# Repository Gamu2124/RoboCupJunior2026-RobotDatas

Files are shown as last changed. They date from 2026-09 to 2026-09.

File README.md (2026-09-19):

# AIR - RoboCupJunior2026 RobotData Repository

RoboCupJunior Soccer Lightweight 2026 シーズンにおいて、**ジャパンオープン優勝**、そして世界大会（韓国・仁川）で**競技優勝・総合優勝・コミュニティ賞**を達成したロボット「AIR」の**設計・開発データを公開するリポジトリ**です。

This repository contains the **design, hardware, and software data of AIR**, the **RoboCupJunior Soccer Lightweight 2026 Japan Open Champion and World Championship Champion**.

---
# 概要 / Overview

本リポジトリは、**次世代のRCJコミュニティおよび学生ロボティクスエンジニアへの情報共有**を目的として公開されています。

2026シーズンの開発で使用した**回路設計、組み込みソフトウェア、マルチマイコンによる分散処理システム、3D CADデータ**など、AIRのロボット開発に関する設計データを公開しています。

We open-source **AIR's robot design and development data** to support the global RCJ community and future student roboticists.

The repository includes **custom PCB designs, multi-MCU embedded firmware, and 3D CAD models** used in the development of AIR during the 2026 season.

---

<table align="center">
  <tr>
    <td align="center">
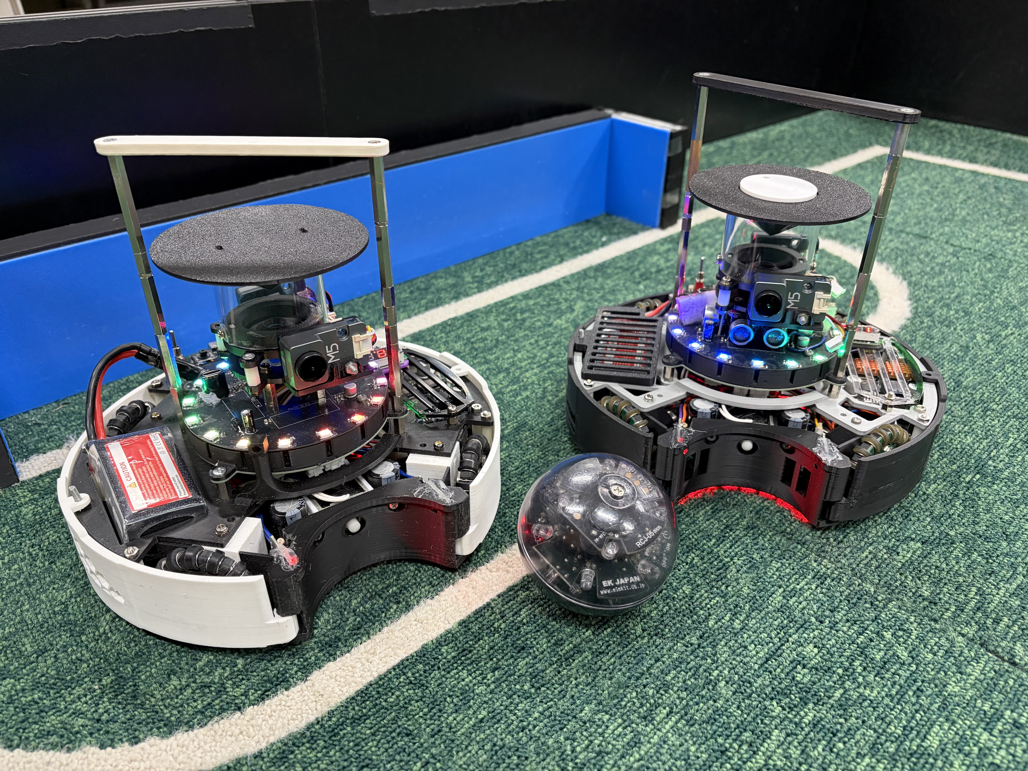
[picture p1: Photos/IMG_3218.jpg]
      
      <br>
      <b>Japan Open 2026</b>
    </td>
    <td align="center">
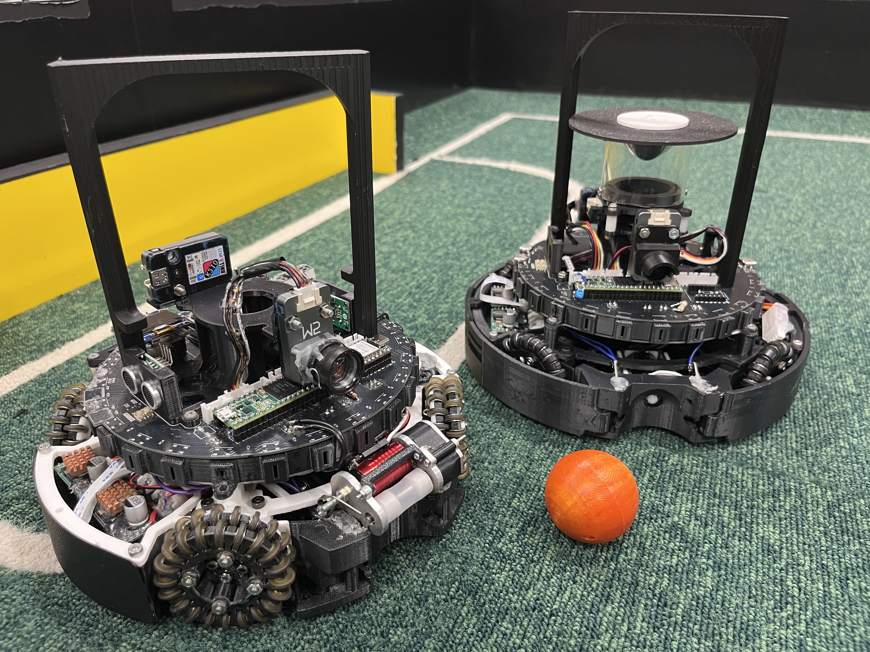
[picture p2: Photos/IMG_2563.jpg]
      
      <br>
      <b>World Championship 2026</b>
    </td>
  </tr>
</table>

---

# 大会実績 / Competition Results

* **RoboCupJunior Japan Open 2026**

  * 🥇 **競技 優勝 / 1st Place**

* **RoboCup World Championship 2026**

  * **Incheon, Republic of Korea**
  * 🥇 **競技 優勝 / Individual 1st Place**
  * 🏆 **総合 優勝 / Overall 1st Place**
  * 🏅 **コミュニティ賞 / Community Award**

---

# 技術的ハイライト / Technical Highlights

AIRのシステムは、**高速なセンサ処理と制御、複数のマイコンへの処理分散、そして競技環境での安定動作**を重視して設計されています。

* **Teensy 4.1を中心としたマルチマイコン分散処理**

  メインマイコンとして**Teensy 4.1**を使用し、複数のUARTを介してボール検出、ライン検出、壁面距離計測、UIなどの処理をサブマイコンへ分散しています。

* **24基のTSSP58038による高密度ボール検出**

  **RP2350Aと24個の赤外線センサ**を使用し、複数方向からのボール検出を高速に行います。得られたセンサ情報から**ボールの方向や距離を推定**し、ロボットの走行制御に利用しています。

* **FreeRTOSを用いた非ブロッキング超音波計測**

  **XIAO ESP32-S3上でFreeRTOSを利用**し、超音波センサによる壁面距離計測をメインの制御処理から分離しています。

* **電源・回路の安定性を重視した設計**

  **DCDCコンバータによる電源系統の分離**、大電流を扱うキッカー回路、複数のマイコン・センサ・モータドライバを統合した電源および信号系統を設計しています。

* **世界大会でのリモートシステムへの対応**

  **世界大会で使用された公式リモートシステム**に対応するための通信・制御機能を実装しています。

---

# リポジトリ構成 / Repository Structure

```text
.
├── Circuit/             # 回路・PCB設計データ (KiCad)
├── Hardware/            # 3D CAD・機械設計データ
├── Program/             # 組み込みソフトウェア・プログラム
├── PresentationSheet/   # プレゼンテーション・資料
├── .gitattributes
└── README.md
```

---

# ハードウェア仕様とシステム進化 / Hardware Architecture & Evolution

AIRのハードウェア構成は、**ジャパンオープンから世界大会（Incheon）にかけて大幅に進化**しました。

| ユニット / System | Japan Open モデル | World Championship (Incheon) モデル |
| --- | --- | --- |
| **Main MCU** | Teensy 4.1 | Teensy 4.1 |
| **Ball Sub MCU & Sensors** | ATmega32U4 + TSSP4038 | **RP2350A + TSSP58038 × 24** |
| **Line Sub MCU & Sensors** | ATmega2560 + B19H1LS / LM393 | **RP2350B + B19H1LS / LM393** |
| **Wall / US MCU** | XIAO ESP32-S3 | XIAO ESP32-S3 |
| **UI & Remote Control** | ESP32 WROOM-32E + OLED + NeoPixel | **XIAO ESP32-S3 + OLED** |
| **Motor Driver** | DRV8432 | **DRV8432** |
| **Kicker System** | CB1037 + Pch/Nch MOSFET | **CB1037 + AQW212 + XL6009** |
| **Power Distribution** | LM2576系電源 | **AP64500SP系電源** |

---

# ソフトウェア機能 / Software Architecture

主に**C/C++およびPython**を用いて開発された、**マルチマイコン分散処理によるロボット制御システム**です。

* **Ball Tracking**

  **24個のTSSP58038**から得られるセンサ情報をRP2350Aで高速処理し、**ボールの方向および距離を推定**します。

* **Line Keep**

  **B19H1LSおよびLM393**を使用したラインセンサシステムにより、フィールド上の白線を検出し、フィールド外への逸脱を防止します。

* **Wall Distance**

  ESP32-S3上で**FreeRTOS**を利用し、超音波センサによる壁面距離計測をバックグラウンドで実行します。

* **Motion Control**

  **IMU（BNO055）から得られる姿勢情報を利用したPIDベースの全方向移動制御**を行います。

* **Strategy State Machine**

  ボール検出、ライン検出、壁面距離、ロボットの状態などの情報をもとに、**試合中の動作を状態機械として制御**します。

* **World Championship Remote Control**

  **世界大会で使用された公式リモートシステムに対応した通信・制御機能**を実装しています。

---

# 開発環境・使用設備 / Development Environment & Equipment

### Software Tools

* **3D CAD**: Autodesk Fusion 360
* **EDA (PCB Design)**: KiCad
* **IDE / Programming**: Visual Studio Code / MaixPy IDE
* **Presentation & Media**: Canva

### Hardware & Manufacturing Equipment

* **3D Printers**: Bambu Lab A1 mini / Bambu Lab P1S / Flashforge Adventurer 5M
* **PCB Fabrication**: JLCPCB
* **Machining / Tools**: 小型CNC加工機

---

# CAD設計データ / CAD Models

AIRを構成する**カスタム機械部品をAutodesk Fusion 360で設計**しています。

主な設計データには以下が含まれます。

* **シャーシ構造** / Chassis
* **キッカーユニット** / Kicker Unit
* **センサマウント各種** / Sensor Mounts
* **オムニホイールモジュール** / Omni Wheel Modules
* **ドリブラー機構** / Dribbler Mechanism

---

# 公開基板データ / PCB Designs

ロボットに使用した**自作基板のKiCad設計データ**を公開しています。

## 日本大会機

1. **メイン基板 (`main_unit`)**
   各種マイコン・センサ・制御系を統合したメイン基板

2. **ボールセンサー基板 (`ball_unit`)**
   **TSSP4038およびATmega32U4**を搭載したボール検出基板

3. **ラインセンサー基板 (`line_unit`)**
   **B19H1LS、LM393、ATmega2560**を搭載したライン検出基板

4. **電源基板 (`power_unit`)**
   **LM2576**を使用した電源基板

5. **モータドライバ基板 (`md_unit`)**
   **DRV8432**を使用したモータドライバ基板

6. **キッカー制御基板 (`kicker_unit`)**
   キッカー用の**大電流スイッチング・絶縁回路**

## 世界大会機

1. **メイン基板 (`main_unit`)**
   各種マイコン・IMU・UIなどを統合したメイン基板

2. **ボールセンサー基板 (`ball_unit`)**
   **TSSP58038 × 24およびRP2350A**を搭載した高密度ボール検出基板

3. **ラインセンサー基板 (`line_unit`)**
   **B19H1LS、LM393、RP2350B**を搭載したライン検出基板

4. **電源基板 (`power_unit`)**
   **AP64500SP**を使用した電源基板

5. **モータドライバ基板 (`md_unit`)**
   **DRV8432**を使用したモータドライバ基板

6. **キッカー制御基板 (`kicker_unit`)**
   **昇圧回路、大電流スイッチング回路、AQW212**を使用したキッカー制御基板

---

# スポンサー / Sponsors

本プロジェクトの活動を支援していただいたスポンサー・団体の皆様に、心より感謝申し上げます。

* **JLCPCB**
  https://jlcpcb.com/

* **DigiKey**
  https://www.digikey.jp/

* **株式会社人機一体**
  https://www.jinki.jp/

* **MAXON**
  https://maxonjapan.com/

* **タカハ機工株式会社**
  https://www.takaha.co.jp/

* **株式会社システムアイインターナショナル**
  https://www.systemi.com/

* **ライフ&キャリアコンサルティング LACIQUE**
  https://www.lacique.com/

* **医療法人社団 翠会 水口病院**
  https://www.minakuchi-hp.or.jp/

* **JOJISTABLE**
  https://x.com/JojiStable

* **立命館守山高校 & 立命館大学**
  https://www.mrc.ritsumei.ac.jp/
  https://www.ritsumei.ac.jp/

---

# チーム情報・お問い合わせ / Team Information & Contact

## AIR

**RoboCupJunior Soccer Lightweight & Infrared Team from Japan**

**World Champion 2026**

### チーム実績 / Team History

* **2025 シーズン**

  * RoboCupJunior Japan Open 2025 🥉 **3位**
  * RoboCup World Championship 2025
    Salvador, Brazil 🥉 **Individual 3rd Place**

* **2026 シーズン**

  * RoboCupJunior Japan Open 2026 🥇 **優勝**
  * RoboCup World Championship 2026
    Incheon, Republic of Korea 🏆 **Individual 1st Place**
  * 🏅 **Community Award**

---

### お問い合わせ・ご質問 / Contact Information

本リポジトリの内容、設計データ、その他技術的なご質問やお問い合わせについては、以下よりご連絡ください。

* **X (Twitter) DM**: [@Air_Gamu_rcj](https://x.com/Air_Gamu_rcj)

* **Email**: [airkorea2026@gmail.com](mailto:airkorea2026@gmail.com)

### 公式メディア・SNS / Links

* **X (Twitter)**: [@Air_3838](https://x.com/Air_3838)

* **YouTube**: [AIR-RCJ Channel](https://www.youtube.com/@AIR-RCJ)

* **note**: [AIR Official note](https://note.com/air_rcj)

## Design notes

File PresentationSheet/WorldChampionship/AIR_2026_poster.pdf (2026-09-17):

# LiPo & SPEED DROP COMPENSATION

# TEAM ABSTRACT

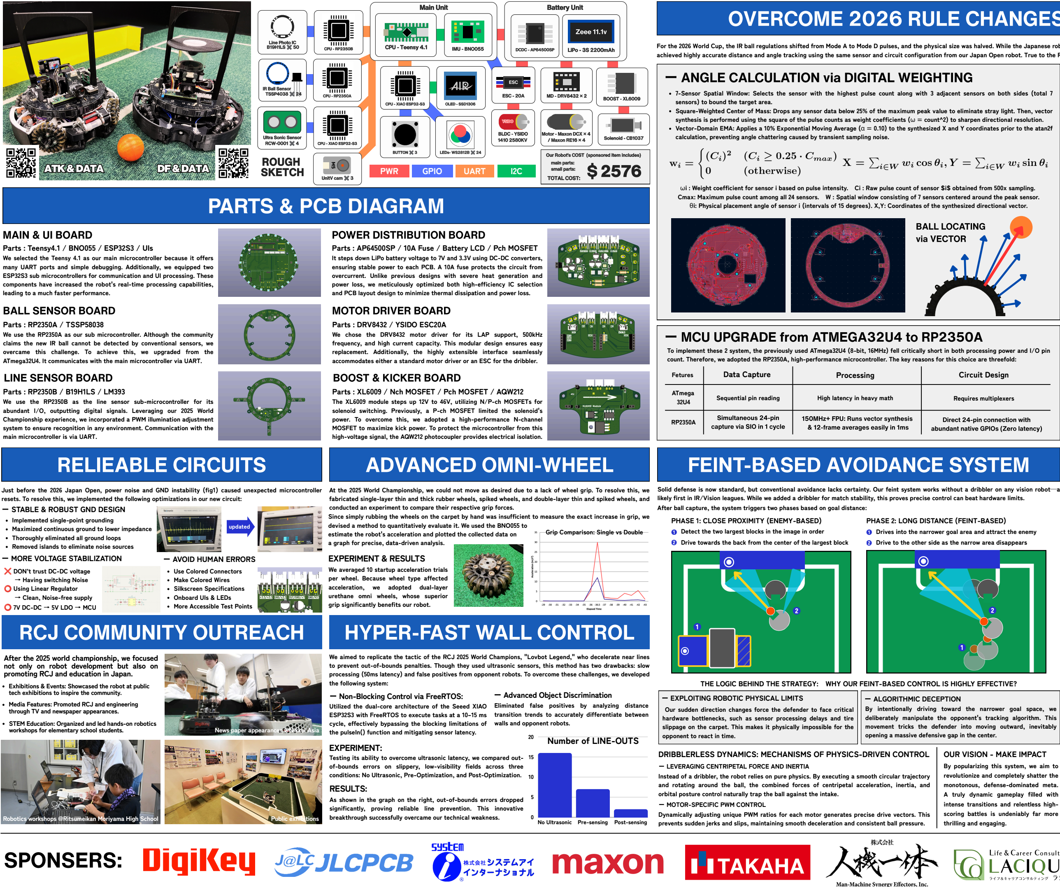
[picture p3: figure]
PARTS & PCB DIAGRAM; RELIEABLE CIRCUITS; RCJ COMMUNITY OUTREACH; ー STABLE & ROBUST GND DESIGN; HYPER-FAST WALL CONTROL; ADVANCED OMNI-WHEEL; ZZeeeeee 1111..11vv; EXPERIMENT:; RESULTS:; No Ultrasonic Pre-sensing Post-sensing; BBLLDDCC -⁻ YYSSIIDDOO; 11441100 22558800KKVV; BLDC - YSIDO; ー EXPLOITING ROBOTIC PHYSICAL LIMITS; opponent to react in time.; ❌ DON’t trust DC-DC voltage → Having switching Noise; → Clean, Noise-free supply; IIRR BBaallll SSeennssoorr TTSSSSPP44003388 ✖ 24; IR Ball Sensor; TSSP4038 ✖️; LLiiPPoo -⁻ 33SS 22220000mmAAhh; CCPPUU -⁻ RRPP22335500AA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

# OVERCOME 2026 RULE CHANGES: A PROVEN IR SENSOR SOLUTION

# OUR CONCEPTS

BASICS | STABLE | DELICACY | CHALLENGE

# ROBOT ALGORITHMS

# FEINT-BASED AVOIDANCE SYSTEM

We are Team AIR. We are a team of three Ritsumeikan university students. We work daily to build robots combining precision control with high mobility for unprecedented, overwhelming performance. After securing 3rd place nationally and globally at RCJ 2025, we won 1st place in Japan at RCJ 2026. This year, we continue competing in the same league to achieve our ultimate goal: winning the World Championship.
Our RCJ journey began six years ago. While we previously dedicated 10 hours a week to development during middle and high school, relocating to separate university campuses has reduced our joint activity time to about 4 hours a week. Despite this challenge, we have never given up and persistently pursue our development.

❷

❶

❷

Our sudden direction changes force the defender to face critical hardware bottlenecks, such as sensor processing delays and tire slippage on the carpet. This makes it physically impossible for the

ー ALGORITHMIC DECEPTION
By intentionally driving toward the narrower goal space, we deliberately manipulate the opponent's tracking algorithm. This movement tricks the defender into moving outward, inevitably opening a massive defensive gap in the center.

### DRIBBLERLESS DYNAMICS: MECHANISMS OF PHYSICS-DRIVEN CONTROL

tssp | IR
tssp | IR

At the 2025 World Championship, we could not move as desired due to a lack of wheel grip. To resolve this, we fabricated single-layer thin and thick rubber wheels, spiked wheels, and double-layer thin and spiked wheels, and conducted an experiment to compare their respective grip forces.
Since simply rubbing the wheels on the carpet by hand was insufficient to measure the exact increase in grip, we devised a method to quantitatively evaluate it. We used the BNO055 to
estimate the robot's acceleration and plotted the collected data on
a graph for precise, data-driven analysis.

## ー MCU UPGRADE from ATMEGA32U4 to RP2350A

### Parts : XL6009 / Nch MOSFET / Pch MOSFET / AQW212

The XL6009 module steps up 12V to 46V, utilizing N/P-ch MOSFETs for solenoid switching. Previously, a P-ch MOSFET limited the solenoid's power. To overcome this, we adopted a high-performance N-channel MOSFET to maximize kick power. To protect the microcontroller from this high-voltage signal, the AQW212 photocoupler provides electrical isolation.

# ⭕️ Using Linear Regulator

Used for
programming

Captain, Electric:
ASAHIUCHIDA | KENGONAKAZAWA

HHaarrddwwaarree::

### KOSUKEKANO

SSooffttwwaarree::
YouTube | GitHub | Blog | X (Twitter)

## JAPAN -KEIJINA

## INFRAREDLEAGUE

### Parts : Teensy4.1 / BNO055 / ESP32S3 / UIs

We selected the Teensy 4.1 as our main microcontroller because it offers many UART ports and simple debugging. Additionally, we equipped two ESP32S3 sub microcontrollers for communication and UI processing. These components have increased the robot's real-time processing capabilities,

We use the RP2350A as our sub microcontroller. Although the community claims the new IR ball cannot be detected by conventional sensors, we overcame this challenge. To achieve this, we upgraded from the ATmega32U4. It communicates with the main microcontroller via UART.

We use the RP2350B as the line sensor sub-microcontroller for its abundant I/O, outputting digital signals. Leveraging our 2025 World Championship experience, we incorporated a PWM illumination adjustment system to ensure recognition in any environment. Communication with the

## Tools: Bringing Ideas to Life

Designs

Programmings

Managements

・KiCad
Used for
develop PCB

・KiCad
Used for design
our components
・VScode | ・MaixPy IDE Used for debugg our cameras

・GitHub
Used for manage
our programs

・Discord
Used for sharing idea
or communicate

Previously, AIR’s robots were designed around the concepts of "basics" and "stability.

" However, we realized that staying within this mindset kept us somewhat immature, and we felt we could never achieve overwhelming victories by simply continuing with this old concept.

Therefore, for this fiscal year, we decided to add the "Right Phase" to our concept, in addition to the previous "Left Phase.

"

At the 2025, we found that many international teams successfully used components and algorithms overlooked in Japan due to preconceptions. This inspired our "Challenge" to import and explore these new technologies. We also pursued "Delicacy"

-retaining explosive power while shifting from unrefined, hyperactive movements to a controlled, powerful presence, alongside refining our base system.

To achieve this, we minimized hardware development time by avoiding drastic changes, shifting our schedule to allocate maximum time to programming. Therefore, this year’s robot is based on our Japan Championship machine, with the vast majority of parts standardized between both units.

### Parts : AP64500SP / 10A Fuse / Battery LCD / Pch MOSFET

It steps down LiPo battery voltage to 7V and 3.3V using DC-DC converters, ensuring stable power to each PCB. A 10A fuse protects the circuit from overcurrent. Unlike previous designs with severe heat generation and power loss, we meticulously optimized both high-efficiency IC selection and PCB layout design to minimize thermal dissipation and power loss.

We chose the DRV8432 motor driver for its LAP support, 500kHz frequency, and high current capacity. This modular design ensures easy replacement. Additionally, the highly extensible interface seamlessly accommodates either a standard motor driver or an ESC for the dribbler.

Just before the 2026 Japan Open, power noise and GND instability (fig1) caused unexpected microcontroller resets. To resolve this, we implemented the following optimizations in our new circuit:

ー MORE VOLTAGE STABILIZATION | ー AVOID HUMAN ERRORS

Maximized continuous ground to lower impedance

Removed islands to eliminate noise sources

# ⭕️ 7V DC-DC → 5V LDO → MCU

For the 2026 World Cup, the IR ball regulations shifted from Mode A to Mode D pulses, and the physical size was halved. While the Japanese robotics community considered conventional sensor designs unusable under these new constraints, we challenged this assumption. We successfully achieved highly accurate distance and angle tracking using the same sensor and circuit configuration from our Japan Open robot. True to the RoboCup spirit of open source, we share our complete design—composed of the following four elements—to support the community's future:

ー ANGLE CALCULATION via DIGITAL WEIGHTING | ー DISTANCE SENSING via PULSE WIDTH
7-Sensor Spatial Window: Selects the sensor with the highest pulse count along with 3 adjacent sensors on both sides (total 7 Square-Weighted Center of Mass: Drops any sensor data below 25% of the maximum peak value to eliminate stray light. Then, vector synthesis is performed using the square of the pulse counts as weight coefficients (ω = count^2) to sharpen directional resolution. Vector-Domain EMA: Applies a 10% Exponential Moving Average (α = 0.10) to the synthesized X and Y coordinates prior to the atan2f calculation, preventing angle chattering caused by transient sampling noise. | 500x Oversampling & 12-Frame Temporal Buffer: Performs 500 direct GPIO reads per sampling loop to detect micro-pulses. The results are stored in a 12-frame moving average buffer for time-domain noise reduction. Top-12 Spatial Integration: Identifies the peak sensor and averages the time-smoothed values of the 12 closest surrounding sensors. This spatial integration effectively averages out localized floor reflections and signal scattering. Dynamic Hysteresis Filter: Implements a dual-mode thresholding system. If the variance between the new raw distance and the previous state is under 20, the output is locked to prevent jitter. If it exceeds 20, the system transitions to tracking mode using a 20% blend rate to follow rapid ball movements.

ωi : Weight coefficient for sensor i based on pulse intensity.　Ci : Raw pulse count of sensor $i$ obtained from 500x sampling. Cmax: Maximum pulse count among all 24 sensors. W : Spatial window consisting of 7 sensors centered around the peak sensor. θi: Physical placement angle of sensor i (intervals of 15 degrees). X,Y: Coordinates of the synthesized directional vector. Si: 12-frame temporal moving average of sensor i at time t. Ci[t-k]: Raw pulse count of sensor i recorded k frames ago.
Draw: Raw distance integrated from the 12 spatial sensors around the peak.
Smax+d: Smoothed pulse count of the sensor located $d$ steps away from the peak.

15cm Enriched Board Diameter (Up from 10cm): Prevents the robot frame from blocking IR signals, eliminating blind spots for stable angle and distance tracking across the entire field.

To implement these 2 system, the previously used ATmega32U4 (8-bit, 16MHz) fell critically short in both processing power and I/O pin count. Therefore, we adopted the RP2350A, high-performance microcontroller. The key reasons for this choice are threefold:

This system requires uniform IR pulse reception. Due to the smaller ball size hindering close-range detection, we implemented two hardware optimizations:

BALL LOCATING

via VECTOR

OF | OF | OF | OF
DF | DF | DF

### After the 2025 world championship, we focused not only on robot development but also on

Media Features: Promoted RCJ and engineering

Exhibitions & Events: Showcased the robot at public tech exhibitions to inspire the community.

STEM Education: Organized and led hands-on robotics

"Narrow & Deep" Sensor Shielding: Narrowed the slit width by 1cm and recessed the sensors 2cm backward. This sharpens directional selectivity and drastically eliminates false positives from stray reflections.

During the 2025 season, we discovered that the robot's movements differed between testing and actual matches due to a decrease in motor rotation speed caused by a drop in battery voltage. The method to resolve this is described below.

### ー Option 1: Time-based control

### ー Option 2: Voltage-based control

First, we devised a time-based system increasing speed to
compensate for discharge. However, it was incompatible with power-off states, and motor usage was inconsistent.

Secondly, a voltage-based system was devised to compensate for dropping motor voltage due to power supply depletion. However, required circuit modifications were a concern.

We adopted option 2 for stability, using a resistive divider to read the supply voltage percentage as an analog input to the Teensy 4.1.

### Experiment: Measure and compare robot travel time across

the court at various supply voltages.

We aimed to replicate the tactic of the RCJ 2025 World Champions,
to prevent out-of-bounds penalties. Though they used ultrasonic sensors, this method has two drawbacks: slow processing (50ms latency) and false positives from opponent robots. To overcome these challenges, we developed

Utilized the dual-core architecture of the Seeed XIAO
ESP32S3 with FreeRTOS to execute tasks at a 10–15 ms cycle, effectively bypassing the blocking limitations of the pulseIn() function and mitigating sensor latency.

Eliminated false positives by analyzing distance transition trends to accurately differentiate between

These results confirm the high effectiveness of this control system, which successfully maintained a constant speed regardless of the voltage level.

High latency in heavy math

150MHz+ FPU: Runs vector synthesis

& 12-frame averages easily in 1ms

Requires multiplexers

Direct 24-pin connection with

abundant native GPIOs (Zero latency)

Data Capture | Processing | Circuit Design

Testing its ability to overcome ultrasonic latency, we compared out-of-bounds errors on slippery, low-visibility fields across three conditions: No Ultrasonic, Pre-Optimization, and Post-Optimization.

As shown in the graph on the right, out-of-bounds errors dropped significantly, proving reliable line prevention. This innovative breakthrough successfully overcame our technical weakness.

Previously, our camera-less algorithm failed at the Japan tournament due to hardware limits. Learning from this, we retained our innovative software concepts while thoroughly elevating our hardware completeness for the world stage. This hard-won experience and mindset remain deeply embedded in our team today.
Based on these experiences, our major advancements this year feature a vision-based opponent avoidance algorithm for difficult shooting angles, software that quickly adapted to rule changes and the new ball using conventional sensors, and a reliability-enhancing UI. Furthermore, we implemented a custom dribbler, a system resilient to voltage drops, and a stable, heat-free modular power supply. This poster highlights these technical breakthroughs.

Solid defense is now standard, but conventional avoidance lacks certainty. Our feint system works without a dribbler on any vision robot—a likely first in IR/Vision leagues. While we added a dribbler for match stability, this proves precise control can beat hardware limits.
After ball capture, the system triggers two phases based on goal distance:

Detect the two largest blocks in the image in order
Drive towards the back from the center of the largest block

Drives into the narrower goal area and attract the enemy Drive to the other side as the narrow area disappears

THE LOGIC BEHIND THE STRATEGY: WHY OUR FEINT-BASED CONTROL IS HIGHLY EFFECTIVE?

Instead of a dribbler, the robot relies on pure physics. By executing a smooth circular trajectory and rotating around the ball, the combined forces of centripetal acceleration, inertia, and orbital posture control naturally trap the ball against the intake.

ー LEVERAGING CENTRIPETAL FORCE AND INERTIA

Dynamically adjusting unique PWM ratios for each motor generates precise drive vectors. This prevents sudden jerks and slips, maintaining smooth deceleration and consistent ball pressure.

revolutionize and completely shatter the

intense transitions and relentless high-

Our Robot’s COST (sponsored item includes)

Narrow
Depper

※ logos are bring from official websites

Robotics workshops @Ritsumeikan Moriyama High School | Public exhibitions

## ー REDESIGN: IR RECEPTION BOUNDARY CONTROL

360-DEGREE FULL
DETECTION SYSTEM

We averaged 10 startup acceleration trials

Uses the ball's angle and distance to flank it via the shortest path, whether still or moving.

After capturing, the robot aligns itself toward the goal and kicks, thereby evading enemy robots.

The robot traces along the line to transport the ball, while remaining resilient against physical pushing.

The robot can force the ball into the goal area, directly leading to a score.

The robot tracks the line near the goal, and it also works well on diagonal paths.

When the ball stays in front for a set time, the robot kicks it to avoid enemies.

When off the line, the robot goes back to the goal, which keeps it running well.

When the defender is out of the court, the attacker changes its role via Communication.

OF&DF

A program to retrieve this ball distance has been uploaded to GitHub. You can access it via the link on the right.

Comparison of Japan Open & World Champion ship Systems

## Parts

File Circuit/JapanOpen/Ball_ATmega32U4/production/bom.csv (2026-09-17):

Designator | Footprint | Quantity | Value | LCSC Part #
32U4_1, 32U4_2 | SOT-23 | 2 | BSS138 | C192057
A1, A10, A11, A12, A13, A14, A15, A16, A2, A3, A4, A5, A6, A7, A8, A9 | XDCR_TSSP4038 | 16 | TSSP4038
C1 | CP_Radial_D5.0mm_P2.50mm | 1 | 150 | C59923
C10 | 0805 | 1 | 10u | C1713
C11, C12, C3, C4, C5, C6, C7, C9 | 0603 | 8 | 0.1u | C1581
C13 | CP_Radial_D5.0mm_P2.00mm | 1 | 47μf
C14, C16, C17, C18, C19, C20, C21, C22, C23, C24, C25, C26, C27, C28, C29, C8 | 0603 | 16 | 0.1 | C1581
C15 | 0603 | 1 | 0.1 | C1848
C2 | 1206 | 1 | 1u | C1848
D10, D11, D12, D13, D14, D15, D16, D17, D18, D19, D20, D5, D6, D7, D8, D9 | LED_WS2812B_PLCC4_5.0x5.0mm_P3.2mm | 16 | WS2812B
D2 | D_A-405_P10.16mm_Horizontal | 1 | D_Schottky
D3 | D_SOD-123F | 1 | D
FFC1 | TE_84952-6_1x06-1MP_P1.0mm_Horizontal | 1 | Conn_01x06_Socket
J1 | PinHeader_2x02_P2.54mm_Vertical | 1 | Conn_02x02_Odd_Even
J11 | PinSocket_2x03_P2.54mm_Vertical | 1 | Conn_02x03_Odd_Even
J3 | PinHeader_2x02_P2.54mm_Vertical | 1 | Conn_02x02_Counter_Clockwise
J4 | PinSocket_1x04_P2.54mm_Vertical | 1 | USS_1
J5 | PinSocket_1x04_P2.54mm_Vertical | 1 | USS_3
J6 | PinSocket_1x04_P2.54mm_Vertical | 1 | USS_2
J7 | PinSocket_1x04_P2.54mm_Vertical | 1 | USS_4
J8 | NELTRON_5077CR-16SMC2-BK-TR | 1 | TYPE-C_32U4
J9 | NELTRON_5077CR-16SMC2-BK-TR | 1 | TYPE-C_main
R1, R2, R3, R4 | 1206 | 4 | 22 | C17958
R10, R11, R14, R9 | 1206 | 4 | 10k | C1489
R12, R18, R6 | 1206 | 3 | 110 | C17909
R13, R17, R19, R8 | 0603 | 4 | 5.1k | C26033
R5, R7 | 1206 | 2 | 10k | C1489
SW1 | Switch_SKRPABE010 | 1 | SW_Push
U1 | TQFP-44_10x10mm_P0.8mm | 1 | ATmega32U4-A | C44854
U2 | XIAO-ESP32-S3-SMD | 1 | XIAO-ESP32-S3-DIP
U3 | TO-252-2 | 1 | LDO_3v3
XTAL1 | CSTNE16M0V530000R0_MUR | 1 | XTAL_32U4

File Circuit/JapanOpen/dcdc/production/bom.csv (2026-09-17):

Designator | Footprint | Quantity | Value | LCSC Part #
C1 | C_Radial_D6.3mm_H5.0mm_P2.50mm | 1 | 100u
C10, C11 | 0603 | 2 | 0.1u | C1581
C12 | CP_Radial_D5.0mm_P2.00mm | 1 | 47u | C3337
C2 | C_Radial_D10.0mm_H12.5mm_P5.00mm | 1 | 1000u
C3, C4, C5, C8 | 0603 | 4 | 0.1
C9 | 0805 | 1 | 10u | C1713
D1, D2 | D_SOD-123F | 2 | D
D3 | 0603 | 1 | RED
D5 | 0603 | 1 | GREEN
F1 | Fuseholder_Clip-5x20mm_Keystone_3517_Inline_P23.11x6.76mm_D1.70mm_Horizontal | 1 | Fuse
J1 | NELTRON_5077CR-16SMC2-BK-TR | 1 | TYPE-C_ESP32
L1 | L_Sunlord_MWSA1204S-1R0 | 1 | 100u
LINE_1, MAIN_PSU1, MAIN_UART1, UI_1 | JST_XH_B2B-XH-A_1x02_P2.50mm_Vertical | 4 | Conn_01x02_Socket
LIPO_1 | AMASS_XT30U-M_1x02_P5.0mm_Vertical | 1 | XT30_IN
MDR_1 | JST_XH_B3B-XH-A_1x03_P2.50mm_Vertical | 1 | Conn_01x03_Socket
OLED_1 | PinSocket_1x02_P2.54mm_Vertical | 1 | Conn_01x02_Socket
Q1 | TO-252-2 | 1 | PMOS
R1 | R_Axial_DIN0207_L6.3mm_D2.5mm_P10.16mm_Horizontal | 1 | 10k
R2 | R_Axial_DIN0207_L6.3mm_D2.5mm_P10.16mm_Horizontal | 1 | 10k | C1489
R3 | 0603 | 1 | 4.7k | C26033
R4 | R_Axial_DIN0207_L6.3mm_D2.5mm_P10.16mm_Horizontal | 1 | 3.3k | C26033
R5 | R_Axial_DIN0207_L6.3mm_D2.5mm_P10.16mm_Horizontal | 1 | 10k | C26033
R6, R9 | 0603 | 2 | 5.1k | C26033
R7 | 1206 | 1 | 110 | C17909
R8 | 1206 | 1 | 56 | C17909
SBD1 | D_A-405_P10.16mm_Horizontal | 1 | D
SBD2 | D_A-405_P10.16mm_Horizontal | 1 | SBD
SW1 | PinSocket_1x02_P2.54mm_Vertical | 1 | SW_SPST
SW2 | Switch_SKRPABE010 | 1 | SW_Push
U1 | TO-263-5_TabPin6 | 1 | LM2576SX-5.0_NOPB
U2 | MSOP-10_3x3mm_P0.5mm | 1 | CH340E
U3 | TO-252-2 | 1 | LDO_3v3
U4 | SOIC-14_3.9x8.7mm_P1.27mm | 1 | ATtiny814-SS

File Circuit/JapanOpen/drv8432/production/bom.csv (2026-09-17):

Designator | Footprint | Quantity | Value | LCSC Part #
C1, C4, C5, C6, C7 | 0603 | 5 | 0.1u
C2 | C_Elec_8x10.2 | 1 | 220u
C3 | 1206 | 1 | 1u | C1848
D1 | 0603 | 1 | LED
J1, J2 | PinHeader_1x06_P2.54mm_Vertical | 2 | Conn_01x06_Pin
R1 | 0402 | 1 | 47k
R2 | 0603 | 1 | 1
R3 | 0805 | 1 | 25 | C17594
U1 | HSOP-36-1EP_11.0x15.9mm_P0.65mm_SlugUp | 1 | DRV8432

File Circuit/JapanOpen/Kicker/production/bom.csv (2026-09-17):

Designator | Footprint | Quantity | Value | LCSC Part #
50K1 | Potentiometer_Bourns_3314G_Vertical | 1 | R_Trim
BATT_1, SOLE2 | JST_XH_B2B-XH-A_1x02_P2.50mm_Vertical | 2 | Conn_01x02_Socket
C1, C2 | C_Radial_D16.0mm_H31.5mm_P7.50mm | 2 | 2200
C3, C5, C6 | 0603 | 3 | 0.1
C4 | CP_Radial_D5.0mm_P2.00mm | 1 | 100
D1, D4 | D_SOD-323 | 2 | SBD
D2, D3 | D_SOD-123F | 2 | D
K1 | SMDIP-8_W7.62mm | 1 | AQW212EHA
L1 | L_Sunlord_MWSA1204S-1R0 | 1 | 47
LED_D1 | 0603 | 1 | LED
MAIN_1 | JST_XH_B3B-XH-A_1x03_P2.50mm_Vertical | 1 | Conn_01x03_Socket
Q1, Q2 | TO-252-2 | 2 | PMOS
R1 | 1206 | 1 | 2k | C17944
R10, R5 | 1206 | 2 | 1k | C1469
R15, R4 | 2512 | 2 | 3.3k | C31884
R3 | 1206 | 1 | 1.6k | C4908
R6 | 2512 | 1 | 150 | C25471
R7 | 2512 | 1 | 3k | C2934109
R8 | 1206 | 1 | 1.6k | C102100
VR1 | TO-263-5_TabPin6 | 1 | LM2577SX-ADJ_NOPB

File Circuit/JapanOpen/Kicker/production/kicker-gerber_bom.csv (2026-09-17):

Designator | Footprint | Quantity | Value | LCSC Part #
C1, C2 | C_Radial_D18.0mm_H35.5mm_P7.50mm | 2 | 3300
D1 | D_SOD-323_HandSoldering | 1 | SBD
D2, D3 | D_SOD-123F | 2 | D
K1 | SMDIP-8_W7.62mm | 1 | AQW212EHA
LED_D1 | 0603 | 1 | LED
MAIN_1, MAIN_2 | JST_XH_B3B-XH-A_1x03_P2.50mm_Vertical | 2 | Conn_01x03_Socket
Q1 | TO-252-2 | 1 | PMOS
Q2 | TO-220-3_Horizontal_TabDown | 1 | NMOS
R2 | 1206 | 1 | 68
R3 | 1206 | 1 | 1.6k | C4908
R4 | 2512 | 1 | 1k | C31884
R5 | 2512 | 1 | 3.3k | C1469
R6 | 2512 | 1 | 150 | C25471
R7 | 2512 | 1 | 3k | C2934109
R8 | 1206 | 1 | 1.6k | C102100
R9 | 1206 | 1 | 10k
SOLE2 | JST_XH_B2B-XH-A_1x02_P2.50mm_Vertical | 1 | Conn_01x02_Socket

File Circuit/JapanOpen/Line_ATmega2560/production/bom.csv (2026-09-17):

Designator | Footprint | Quantity | Value | LCSC Part #
C10, C11, C7, C8, C9 | 0603 | 5 | 0.1u | C1555
C14 | C_Elec_5x5.4 | 1 | 100u
C16 | C_Elec_4x5.4 | 1 | 1u | C3348
C2 | 0603 | 1 | 0.1
D1, D10, D11, D12, D13, D14, D15, D16, D17, D18, D19, D2, D20, D21, D22, D23, D24, D25, D26, D27, D28, D3, D37, D38, D39, D4, D40, D5, D6, D7, D8, D9 | 0603 | 32 | NJL
D29, D30, D31, D32, D33, D34, D35, D36 | D_SOD-323 | 8 | SBD
J1, LINE_1 | JST_XH_S2B-XH-A-1_1x02_P2.50mm_Horizontal | 2 | Conn_01x02_Socket
J2 | PinHeader_2x02_P2.54mm_Vertical | 1 | Conn_02x02_Counter_Clockwise
J3 | JST_XH_S4B-XH-A_1x04_P2.50mm_Horizontal | 1 | Conn_01x04_Socket
J4, J5, J6 | PinSocket_1x07_P2.54mm_Vertical | 3 | Conn_01x07_Socket
LED_1, LED_10, LED_11, LED_12, LED_13, LED_14, LED_15, LED_16, LED_17, LED_18, LED_19, LED_2, LED_20, LED_21, LED_22, LED_23, LED_24, LED_25, LED_26, LED_27, LED_28, LED_29, LED_3, LED_30, LED_31, LED_32, LED_4, LED_5, LED_6, LED_7, LED_8, LED_9 | 0603 | 32 | LED
R1, R10, R11, R12, R13, R14, R15, R16, R17, R18, R19, R2, R20, R21, R22, R23, R24, R3, R4, R41, R42, R45, R46, R5, R6, R7, R8, R88, R9, R90, R91, R92 | 0603 | 32 | 100k | C23098
R25, R26, R27, R28, R29, R30, R31, R32, R33, R34, R35, R36, R38, R43, R44, R79 | 1206 | 16 | 56 | C17995
R37, R49 | 0603 | 2 | 10k | C23098
R39, R51, R52, R53, R54, R55, R56, R58, R59, R60, R61, R62, R63, R64, R65, R66, R67, R68, R69, R70, R71, R72, R73, R74, R75, R76, R77, R78, R83, R84, R86, R89 | 0603 | 32 | 1k | C23098
R50 | 1206 | 1 | 110 | C17909
U1 | TQFP-100_14x14mm_P0.5mm | 1 | ATmega2560-16A
U10, U11, U12, U13, U14, U15, U16, U17, U2, U3, U4, U5, U6, U7, U8, U9 | SOIC-8_3.9x4.9mm_P1.27mm | 16 | LM393
XTAL1 | CSTNE16M0V530000R0_MUR | 1 | CSTNE16M0V530000R0

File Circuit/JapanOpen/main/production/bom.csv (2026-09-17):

Designator | Footprint | Quantity | Value | LCSC Part #
32U4_1, 32U4_2 | SOT-23 | 2 | BSS138 | C192057
BNO_1, NONE_1 | PinSocket_1x04_P2.54mm_Vertical | 2 | Conn_01x04_Socket
C1 | C_Disc_D5.1mm_W3.2mm_P5.00mm | 1 | 10
C2 | C_Disc_D5.0mm_W2.5mm_P2.50mm | 1 | 0.1
C4, C5 | CP_Radial_D5.0mm_P2.00mm | 2 | 100
C6 | C_Disc_D5.1mm_W3.2mm_P5.00mm | 1 | 10u | C1713
C7, C8 | C_Disc_D5.0mm_W2.5mm_P2.50mm | 2 | 0.1u | C1581
C9 | CP_Radial_D5.0mm_P2.00mm | 1 | 47u | C3337
CAM_1, CAM_2 | JST_XH_B4B-XH-A_1x04_P2.50mm_Vertical | 2 | Conn_01x04_Socket
CATCH_LED1, J3, LINE_1, VIN_1 | JST_XH_B2B-XH-A_1x02_P2.50mm_Vertical | 4 | Conn_01x02_Socket
CATCH_PHOTO1, KICK_1 | JST_XH_B3B-XH-A_1x03_P2.50mm_Vertical | 2 | Conn_01x03_Socket
D1 | D_SOD-123F | 1 | D
J1, J2 | PinSocket_1x24_P2.54mm_Vertical | 2 | Conn_01x24_Socket
J4 | PinHeader_2x02_P2.54mm_Vertical | 1 | Conn_02x02_Odd_Even
J5 | PinSocket_2x03_P2.54mm_Vertical | 1 | Conn_02x03_Odd_Even
MOTOR_1, MULTIPLEX_1 | TE_84952-6_1x06-1MP_P1.0mm_Horizontal | 2 | Conn_01x06_Socket
R1 | R_Axial_DIN0207_L6.3mm_D2.5mm_P10.16mm_Horizontal | 1 | 3.3k
R2 | R_Axial_DIN0207_L6.3mm_D2.5mm_P10.16mm_Horizontal | 1 | 3.3k | C22978
R3, R4, R5, R6 | 0603 | 4 | 10k | C1489
U1 | TO-252-2 | 1 | BD50FC0FP

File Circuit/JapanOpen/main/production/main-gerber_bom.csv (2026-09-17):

Designator | Footprint | Quantity | Value | LCSC Part #
32U4_1, 32U4_2 | SOT-23 | 2 | BSS138 | C192057
BNO_1, NONE_1 | PinSocket_1x04_P2.54mm_Vertical | 2 | Conn_01x04_Socket
C1 | C_Disc_D5.1mm_W3.2mm_P5.00mm | 1 | 10
C10, C4, C5 | CP_Radial_D5.0mm_P2.00mm | 3 | 100
C2 | C_Disc_D5.0mm_W2.5mm_P2.50mm | 1 | 0.1
C6 | C_Disc_D5.1mm_W3.2mm_P5.00mm | 1 | 10u | C1713
C7, C8 | C_Disc_D5.0mm_W2.5mm_P2.50mm | 2 | 0.1u | C1581
C9 | CP_Radial_D5.0mm_P2.00mm | 1 | 47u | C3337
CAM_1, CAM_2, CAM_3 | JST_XH_B4B-XH-A_1x04_P2.50mm_Vertical | 3 | Conn_01x04_Socket
CATCH_LED1, CATCH_LED2, LINE_1, VIN_1 | JST_XH_B2B-XH-A_1x02_P2.50mm_Vertical | 4 | Conn_01x02_Socket
CATCH_PHOTO1, KICK_1 | JST_XH_B3B-XH-A_1x03_P2.50mm_Vertical | 2 | Conn_01x03_Socket
D1 | D_SOD-123F | 1 | D
J1, J2 | PinSocket_1x24_P2.54mm_Vertical | 2 | Conn_01x24_Socket
J3 | PinSocket_1x02_P2.54mm_Vertical | 1 | Conn_01x02_Socket
J4 | PinHeader_2x02_P2.54mm_Vertical | 1 | Conn_02x02_Odd_Even
J5 | PinSocket_2x03_P2.54mm_Vertical | 1 | Conn_02x03_Odd_Even
MOTOR_1 | TE_84952-6_1x06-1MP_P1.0mm_Horizontal | 1 | Conn_01x06_Socket
R1 | R_Axial_DIN0207_L6.3mm_D2.5mm_P10.16mm_Horizontal | 1 | 3.3k
R2 | R_Axial_DIN0207_L6.3mm_D2.5mm_P10.16mm_Horizontal | 1 | 3.3k | C22978
R3, R4, R5, R6 | 1206 | 4 | 10k | C1489
U1 | TO-252-2 | 1 | BD50FC0FP

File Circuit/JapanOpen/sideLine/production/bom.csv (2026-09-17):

Designator | Footprint | Quantity | Value | LCSC Part #
D1, D11, D14, D18, D19, D2, D20, D3, D4, D5, D8 | 0603 | 11 | NJL
D10, D12, D13, D15, D16, D6, D7, D9 | D_SOD-323 | 8 | SBD
J1 | PinSocket_1x07_P2.54mm_Vertical | 1 | Conn_01x07_Socket
LED_1, LED_10, LED_11, LED_12, LED_2, LED_3, LED_4, LED_5, LED_6, LED_7, LED_8, LED_9 | 0603 | 12 | LED
R1, R13, R3, R5, R7, R9 | 1206 | 6 | 56 | C17995
R10, R11, R17, R18, R23, R24, R27, R28, R29, R30, R31 | 0603 | 11 | 1k | C23098
R12, R15, R19, R2, R20, R21, R25, R26, R4, R6, R8 | 0603 | 11 | 100k | C23098
U1, U2, U3, U4, U5, U6 | SOIC-8_3.9x4.9mm_P1.27mm | 6 | LM393

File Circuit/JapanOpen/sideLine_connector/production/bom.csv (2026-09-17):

Designator | Footprint | Quantity | Value | LCSC Part #
J1, J2 | PinSocket_1x07_P2.54mm_Vertical | 2 | Conn_01x07_Socket

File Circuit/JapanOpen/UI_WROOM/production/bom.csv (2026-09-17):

Designator | Footprint | Quantity | Value | LCSC Part #
BZ1 | XDCR_KXG0909P | 1 | Buzzer
C1, C11, C12, C3, C4, C5, C6, C8, C9 | 0603 | 9 | 0.1u | C1581
C10 | CP_Radial_D5.0mm_P2.00mm | 1 | 47u | C3337
C2 | 0603 | 1 | 0.1 | C1581
C7 | C_Disc_D5.1mm_W3.2mm_P5.00mm | 1 | 10u | C1713
D1 | 0603 | 1 | GREEN
D2, D4, D5, D6, D7, D8 | 0603 | 6 | RED
D3 | D_SOD-123F | 1 | D
FFC1 | TE_84952-6_1x06-1MP_P1.0mm_Horizontal | 1 | Conn_01x06_Socket
J1 | NELTRON_5077CR-16SMC2-BK-TR | 1 | TYPE-C_Line
J2 | NELTRON_5077CR-16SMC2-BK-TR | 1 | TYPE-C_ESP32
J3 | JST_XH_B2B-XH-A_1x02_P2.50mm_Vertical | 1 | Conn_01x02_Socket
J4 | PinSocket_1x04_P2.54mm_Vertical | 1 | Conn_01x04_Socket
J5 | JST_XH_S4B-XH-A_1x04_P2.50mm_Horizontal | 1 | Conn_01x04_Socket
NEOPIX1 | SOT-23 | 1 | BSS138 | C192057
R1 | 1206 | 1 | 10k | C26033
R10, R5 | 1206 | 2 | 110 | C17909
R11, R4, R6, R9 | 0603 | 4 | 5.1k | C26033
R2 | R_Axial_DIN0207_L6.3mm_D2.5mm_P10.16mm_Horizontal | 1 | 1k
R3 | 1206 | 1 | 56 | C17909
R7, R8 | 1206 | 2 | 10k | C1489
SW1, SW2, SW3 | Switch_SKRPABE010 | 3 | SW_Push
TACT_1, TACT_2, TACT_3 | SW_PUSH-12mm | 3 | SW_Push
TOGGLE_1 | PinSocket_1x03_P2.54mm_Vertical | 1 | SW_SPDT
U1 | ESP32-WROOM-32 | 1 | ESP32-WROOM-32
U2 | SSOP-10-1EP_3.9x4.9mm_P1mm_EP2.1x3.3mm | 1 | CH340K
U3 | UMT6 | 1 | UMH3N
U4 | TO-252-2 | 1 | BD50FC0FP
U5 | MSOP-10_3x3mm_P0.5mm | 1 | CH340E

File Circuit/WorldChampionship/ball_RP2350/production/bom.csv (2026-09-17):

Designator | Footprint | Quantity | Value | LCSC Part #
A1, A10, A11, A12, A13, A14, A15, A16, A17, A18, A19, A2, A20, A21, A22, A23, A24, A3, A4, A5, A6, A7, A8, A9 | XDCR_TSSP4038 | 24 | TSSP4038
C1, C16, C4 | 0402 | 3 | 4.7
C10, C13 | 0402 | 2 | 15p | C1548
C11, C12, C14, C15, C2, C5, C6, C7, C8, C9 | 0402 | 10 | 0.1
C17 | CP_Elec_6.3x5.7 | 1 | 150 | C249851
C3 | 0402 | 1 | 4.7 | C1872
D1 | 0603 | 1 | BLUE
D2 | 0603 | 1 | GREEN
J1, J2, J3 | PinHeader_2x02_P2.54mm_Vertical | 3 | Conn_02x02_Counter_Clockwise
L1 | Inductor_0806_2016 | 1 | 3.3 | C42411119
R1 | 0402 | 1 | 15 | C22369173
R2 | 0402 | 1 | 30 | C22356186
R3 | 0402 | 1 | 1k | C174178
R4 | 0603 | 1 | 33 | C177281
R6 | 0402 | 1 | 22 | C174144
R7 | 0402 | 1 | 22
U1 | SOIC-8_5.23x5.23mm_P1.27mm | 1 | W25Q128JVS
U2 | Package_QFN-60-1EP_7x7mm_P0.4mm_EP3.4x3.4mm_hand | 1 | RP2350_60QFN
Y1 | Crystal_SMD_3225-4Pin_3.2x2.5mm | 1 | Crystal_GND24 | C20625731

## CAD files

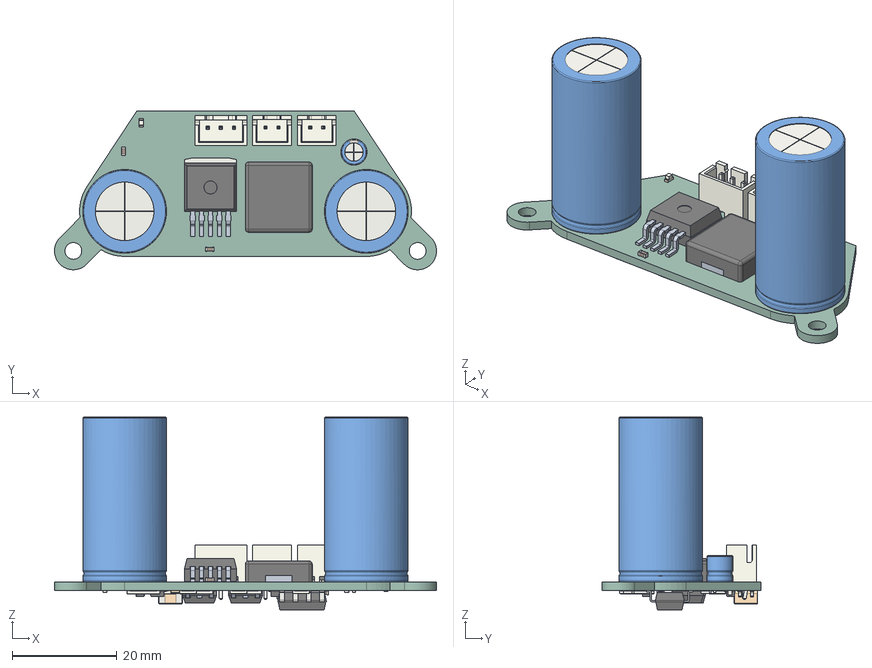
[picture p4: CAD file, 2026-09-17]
Circuit/JapanOpen/Kicker/Kicker_V1.step
73.1 x 30.3 x 36.9 mm
C_Radial_D160mm_H315mm_P750mm x 2
CP_Radial_D50mm_P200mm
JST_B2B_XH_A x 2
CQ assembly x 4
C_0603_1608Metric x 3
JST_B3B_XH_A
LED_0603_1608Metric
R_1206_3216Metric x 5
R_2512_6332Metric x 4
Potentiometer_Bourns_3314G_Vertical
SMDIP_8_W762mm
D_SOD_323
D_SOD_123F x 2
Kicker_V1_PCB

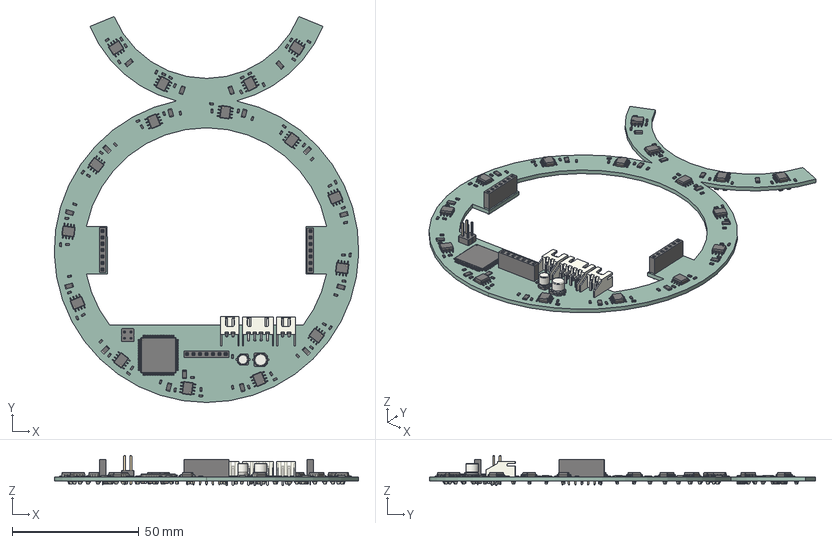
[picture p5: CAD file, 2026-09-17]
Circuit/JapanOpen/Line_ATmega2560/Line_V7_ATmega2560.step
120.3 x 152.5 x 11.9 mm
R_0603_1608Metric x 66
C_Elec_5x54
R_1206_3216Metric x 17
C_Elec_4x54
SOIC_8_39x49mm_P127mm x 16
PinSocket_1x07_P254mm_Vertical x 3
JST_S2B_XH_A_1 x 2
JST_S4B_XH_A
PinHeader_2x02_P254mm_Vertical
TQFP_100_14x14mm_P05mm
LED_0603_1608Metric x 64
C_0603_1608Metric x 6
D_SOD_323 x 8
Line_V7_ATmega2560_PCB

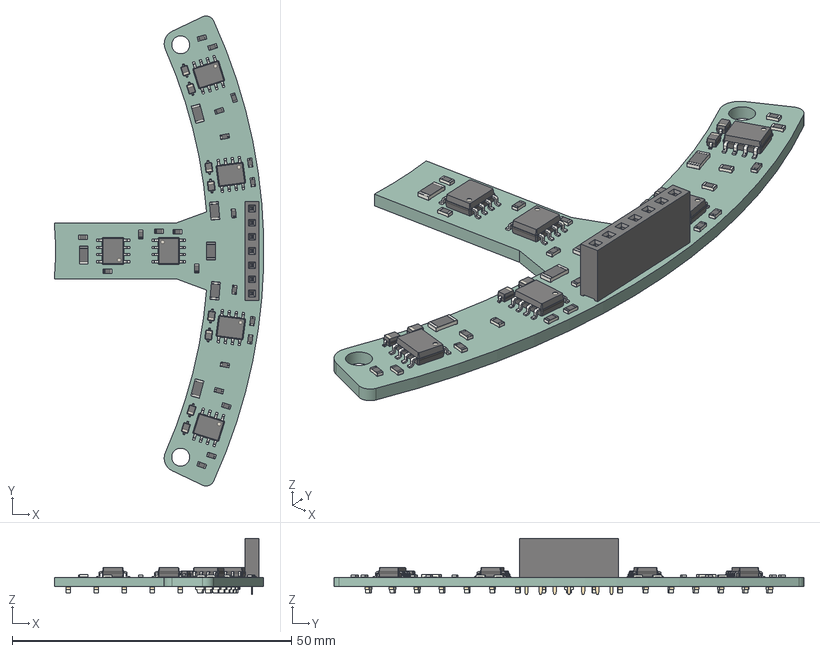
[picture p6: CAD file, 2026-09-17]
Circuit/JapanOpen/sideLine/sideLine_V3.step
37.5 x 84.2 x 10.1 mm
R_0603_1608Metric x 22
PinSocket_1x07_P254mm_Vertical
D_SOD_323 x 8
SOIC_8_39x49mm_P127mm x 6
R_1206_3216Metric x 6
LED_0603_1608Metric x 23
sideLine_V3_PCB

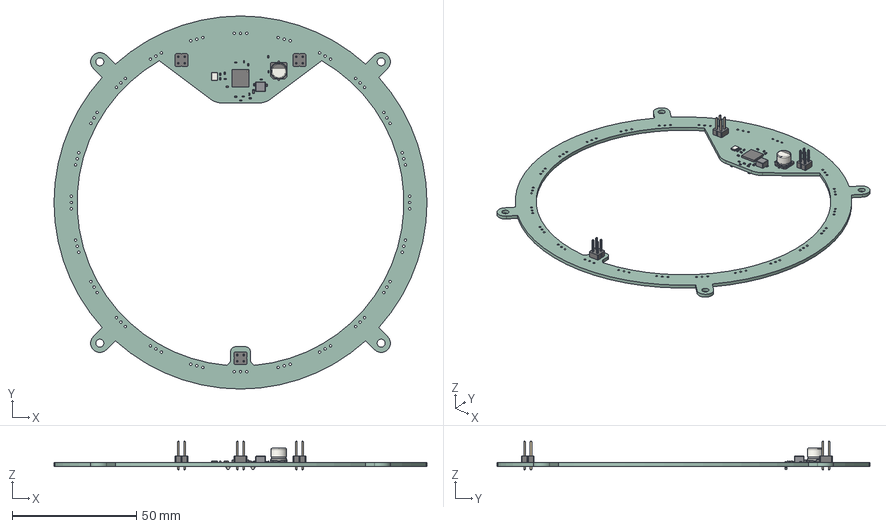
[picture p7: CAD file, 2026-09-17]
Circuit/WorldChampionship/ball_RP2350/ball_2026_v1.step
150.0 x 150.0 x 11.5 mm
C_0402_1005Metric x 16
R_0603_1608Metric
Crystal_SMD_3225-4Pin_3.2x2.5mm
R_0402_1005Metric x 5
QFN-56-1EP_7x7mm_P0.4mm_EP5.6x5.6mm
PinHeader_2x02_P2.54mm_Vertical x 3
L_Abracon_ASPI-0425
CP_Elec_6.3x5.7
LED_0603_1608Metric x 2
ball_2026_v1_PCB

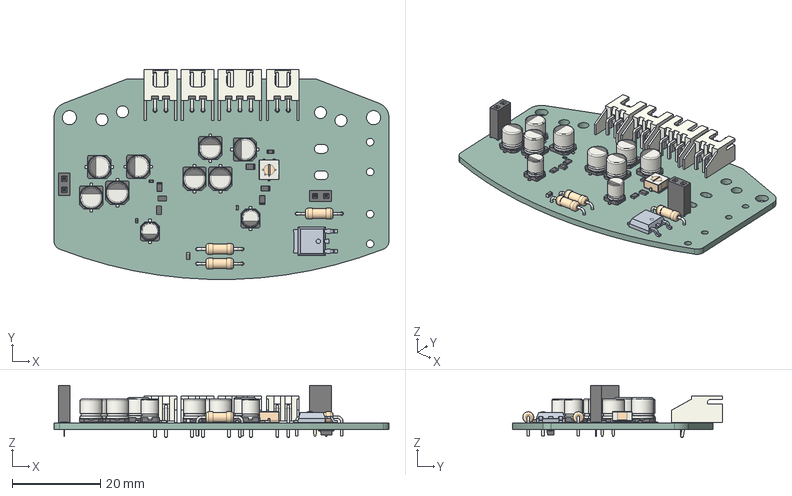
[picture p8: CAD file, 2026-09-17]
Circuit/WorldChampionship/dcdc/dcdc_2026_v1.step
76.1 x 47.6 x 11.9 mm
CP_Elec_5x5.4 x 6
C_0402_1005Metric x 2
CP_Elec_4x5.4 x 2
R_0805_2012Metric x 6
PinSocket_1x02_P2.54mm_Vertical x 2
JST_XH_S2B-XH-A_1x02_P2.50mm_Horizontal x 3
R_Axial_DIN0207_L6.3mm_D2.5mm_P10.16mm_Horizontal x 3
Potentiometer_Bourns_3314J_Vertical
C_0603_1608Metric
dcdc_2026_v1 1.22.1
R_0603_1608Metric
CP_Elec_5x5.7 x 2
R_0402_1005Metric
JST_XH_S3B-XH-A_1x03_P2.50mm_Horizontal
D_SOD-123F
dcdc_2026_v1_PCB

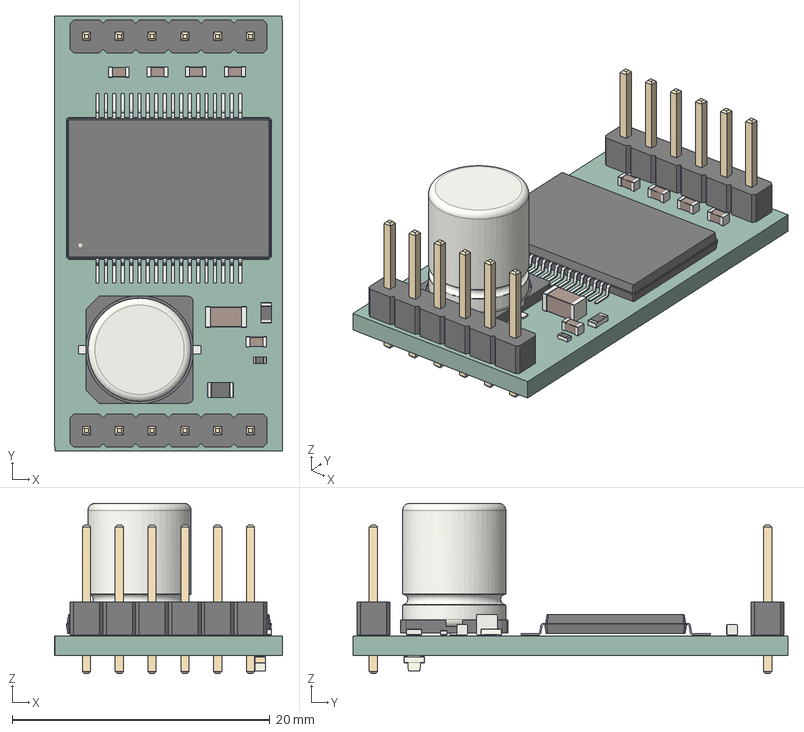
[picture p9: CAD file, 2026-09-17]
Circuit/WorldChampionship/drv8432/drv8432_V3.step
17.7 x 33.7 x 13.2 mm
R_0603_1608Metric
R_0402_1005Metric
C_0603_1608Metric x 5
PinHeader_1x06_P2.54mm_Vertical x 2
C_Elec_8x10.2
R_0805_2012Metric
HSOP-36-1EP_11.0x15.9mm_P0.65mm_SlugUp
C_1206_3216Metric
LED_0603_1608Metric
drv8432_V3_PCB

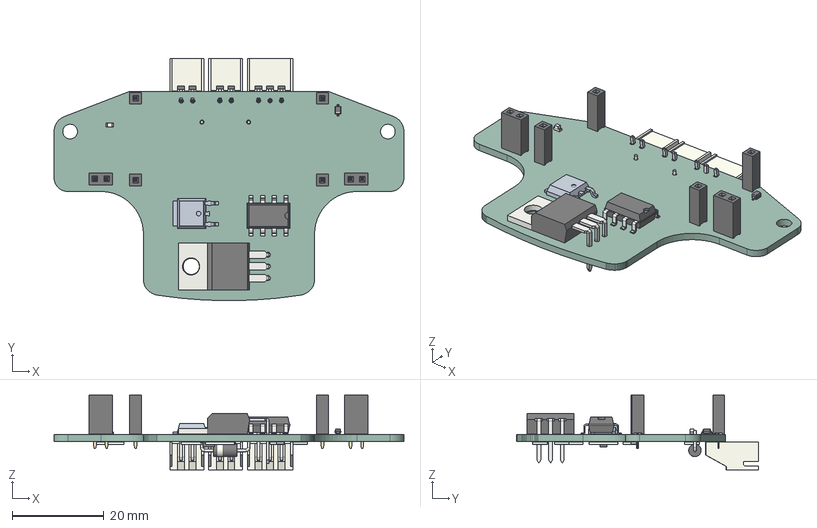
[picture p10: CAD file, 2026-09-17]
Circuit/WorldChampionship/kicker/kick_.step
76.1 x 52.7 x 16.3 mm
PinSocket_1x01_P2.54mm_Vertical x 4
SMDIP-8_W7.62mm
PinSocket_1x02_P2.54mm_Vertical x 2
kick_ 1.7.1
D_SOD-323
TO-220-3_Horizontal_TabDown
LED_0603_1608Metric
R_1206_3216Metric x 4
R_2512_6332Metric x 4
D_A-405_P10.16mm_Horizontal
D_SOD-123F
JST_XH_S2B-XH-A_1x02_P2.50mm_Horizontal x 2
JST_XH_S3B-XH-A_1x03_P2.50mm_Horizontal
kick__PCB

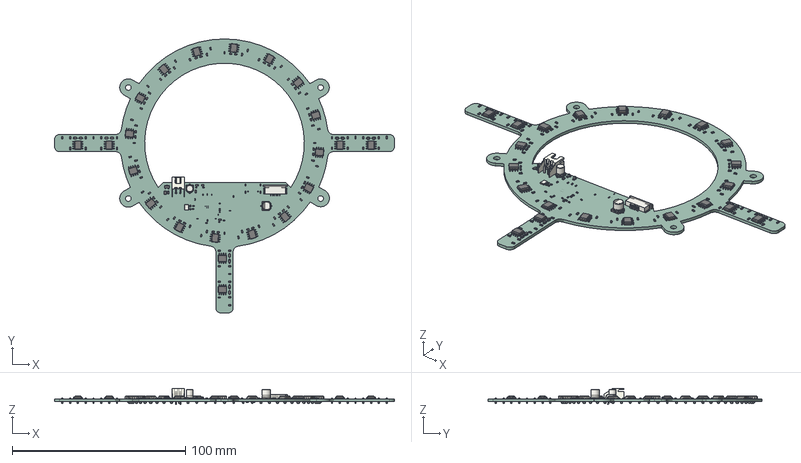
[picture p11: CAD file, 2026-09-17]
Circuit/WorldChampionship/line_RP2350/line_2026_v1.step
196.0 x 158.0 x 9.50 mm
R_0603_1608Metric x 115
R_0402_1005Metric x 5
SOIC-8_3.9x4.9mm_P1.27mm x 22
C_0402_1005Metric x 18
D_SOD-323 x 12
JST_XH_S2B-XH-A_1x02_P2.50mm_Horizontal
C_Elec_4x5.4
LED_0603_1608Metric x 90
CP_Elec_5x5.4
Crystal_SMD_3225-4Pin_3.2x2.5mm
R_0805_2012Metric
SOT-23
TE_84952-6_1x06-1MP_P1.0mm_Horizontal
line_2026_v1_PCB

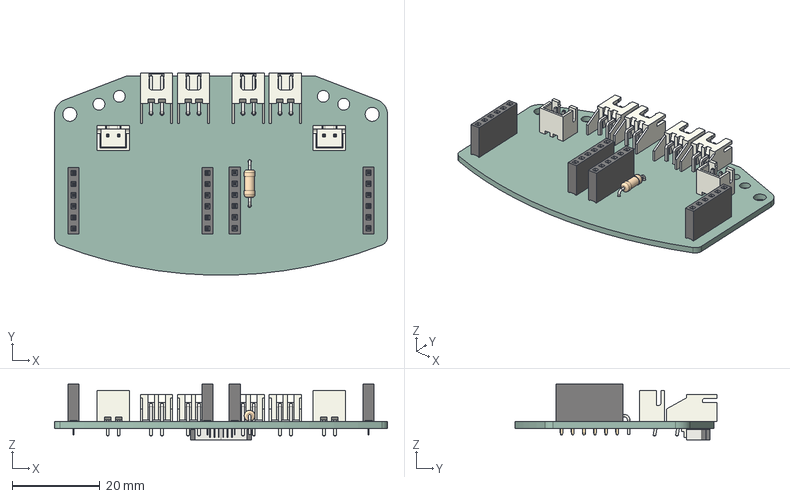
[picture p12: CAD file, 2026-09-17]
Circuit/WorldChampionship/md_board/md_2026_v1.step
76.1 x 46.2 x 12.7 mm
JST_XH_S2B-XH-A_1x02_P2.50mm_Horizontal x 4
R_Axial_DIN0207_L6.3mm_D2.5mm_P10.16mm_Horizontal
JST_XH_B2B-XH-A_1x02_P2.50mm_Vertical x 2
PinSocket_1x06_P2.54mm_Vertical x 4
TE_84952-6_1x06-1MP_P1.0mm_Horizontal
md_2026_v1_PCB

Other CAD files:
Hardware/WorldChampionship/AIR_2026_Robot_ATK.f3z
Hardware/WorldChampionship/AIR_2026_Robot_DEF.f3z

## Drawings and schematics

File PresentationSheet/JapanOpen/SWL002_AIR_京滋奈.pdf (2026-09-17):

基本 | 安定 | 挑戦 | 繊細

# チーム概要 / シーズン目標 / コンセプト

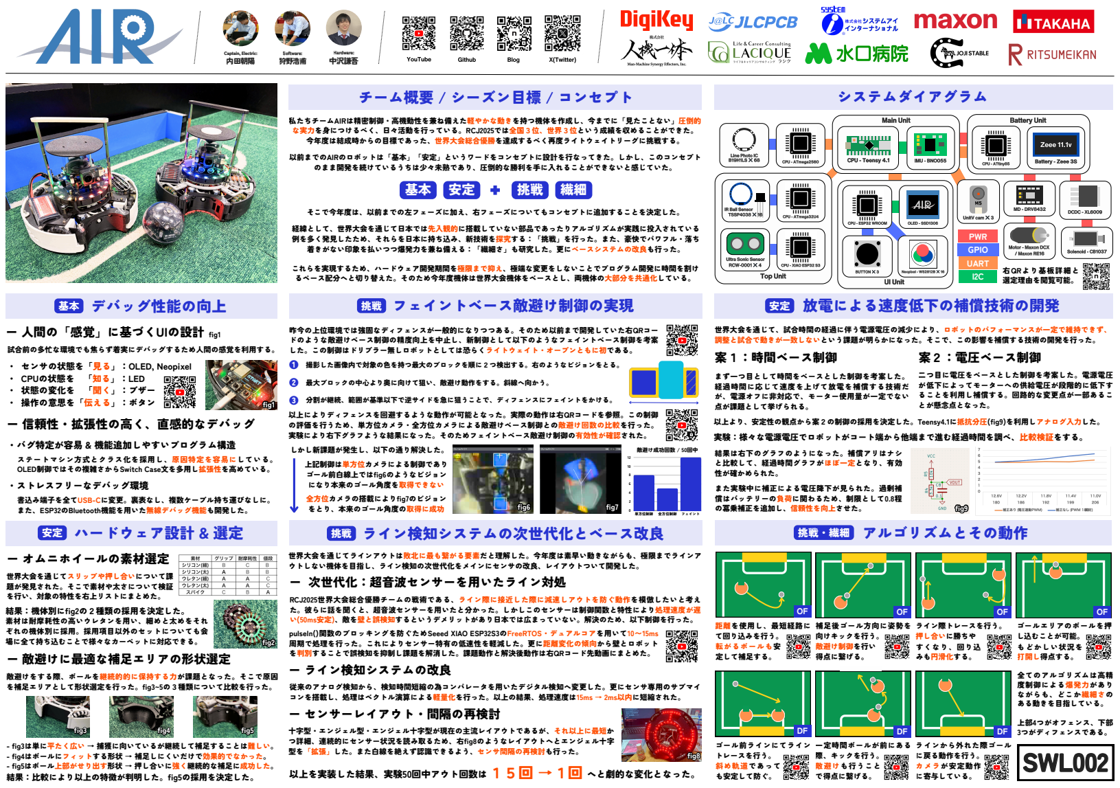
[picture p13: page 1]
SSWWLL000022; ZZeeeeee 1111..11vv; ー オムニホイールの素材選定; 距離を使用し、最短経路に て回り込みを行う。 転がるボールも安 定して補足する。; 補足後ゴール方向に姿勢を 向けキックを行う。 敵避け制御を行い 得点に繋げる。; ライン際トレースを行う。 押し合いに勝ちや すくなり、回り込 みも円滑化する。; ゴールエリアのボールを押 し込むことが可能。 もどかしい状況を 打開し得点する。; ゴール前ラインにてライン トレースを行う。 斜め軌道であって も安定して防ぐ。; 一定時間ボールが前にある 際、キックを行う。 敵避けも行うこと で得点に繋げる。; ラインから外れた際ゴール に戻る動作を行う。 カメラが安定動作 に寄与している。; 敵避け成功回数 / 50回中; 単方位制御; 全方位制御; フェイント; fiig6; TSSP4038 ✖ 16; BBaatttteerryy -- ZZeeeeee 33SS; CCPPUU -- AATTmmeeggaa3322UU44; CCPPUU -- TTeeeennssyy 44..11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

私たちチームAIRは精密制御・高機動性を兼ね備えた軽やかな動きを持つ機体を作成し、今までに「見たことない」圧倒的
な実力を身につけるべく、日々活動を行っている。RCJ2025では全国３位、世界３位という成績を収めることができた。
今年度は結成時からの目標であった、世界大会総合優勝を達成するべく再度ライトウェイトリーグに挑戦する。

以前までのAIRのロボットは「基本」「安定」というワードをコンセプトに設計を行なってきた。しかし、このコンセプト

Line Photo IC

そこで今年度は、以前までの左フェーズに加え、右フェーズについてもコンセプトに追加することを決定した。

IR Ball Sensor
TSSP4038 ✖ 16

UnitV cam ✖ 3 OLED - SSD1306

経緯として、世界大会を通じて日本では先入観的に搭載していない部品であったりアルゴリズムが実践に投入されている
例を多く発見したため、それらを日本に持ち込み、新技術を探究する：「挑戦」を行った。また、豪快でパワフル・落ち
着きがない印象を払いつつ爆発力を兼ね備える：「繊細さ」も研究した。更にベースシステムの改良も行った。

Motor - Maxon DCX
/ Maxon RE16

Ultra Sonic Sensor
RRCCWW⁻-00000011 ✖✖ 44

これらを実現するため、ハードウェア開発期間を極限まで抑え、極端な変更をしないことでプログラム開発に時間を割け
るペース配分へと切り替えた。そのため今年度機体は世界大会機体をベースとし、両機体の大部分を共通化している。

ー 人間の「感覚」に基づくUIの設計

昨今の上位環境では強固なディフェンスが一般的になりつつある。そのため以前まで開発していた右QRコー
ドのような敵避けベース制御の精度向上を中止し、新制御として以下のようなフェイントベース制御を考案
した。この制御はドリブラー無しロボットとしては恐らくライトウェイト・オープンともに初である。
撮影した画像内で対象の色を持つ最大のブロックを順に２つ検出する。右のようなビジョンをとる。
最大ブロックの中心より奥に向けて狙い、敵避け動作をする。斜線へ向かう。
分割が継続、範囲が基準以下で逆サイドを急に狙うことで、ディフェンスにフェイントをかける。

世界大会を通じて、試合時間の経過に伴う電源電圧の減少により、ロボットのパフォーマンスが一定で維持できず、
調整と試合で動きが一致しないという課題が明らかになった。そこで、この影響を補償する技術の開発を行った。
案１：時間ベース制御

試合前の多忙な環境でも焦らず着実にデバッグするため人間の感覚を利用する。
・ センサの状態を「見る」：OLED, Neopixel
・ CPUの状態を 「知る」：LED
・ 状態の変化を 「聞く」：ブザー
・ 操作の意思を「伝える」：ボタン
ー 信頼性・拡張性の高く、直感的なデバッグ

以上によりディフェンスを回避するような動作が可能となった。実際の動作は右QRコードを参照。この制御
の評価を行うため、単方位カメラ・全方位カメラによる敵避けベース制御との敵避け回数の比較を行った。
実験により右下グラフような結果になった。そのためフェイントベース敵避け制御の有効性が確認された。

以上より、安定性の観点から案２の制御の採用を決定した。Teensy4.1に抵抗分圧(fig9)を利用しアナログ入力した。
実験：様々な電源電圧でロボットがコート端から他端まで進む経過時間を調べ、比較検証をする。

結果は右下のグラフのようになった。補償アリはナシ
と比較して、経過時間グラフがほぼ一定となり、有効
性が確かめられた。

書込み端子を全てUSB-Cに変更。裏表なし、複数ケーブル持ち運びなしに。
また、ESP32のBluetooth機能を用いた無線デバッグ機能も開発した。

世界大会を通じてラインアウトは敗北に最も繋がる要素だと理解した。今年度は素早い動きながらも、極限までラインア
ウトしない機体を目指し、ライン検知の次世代化をメインにセンサの改良、レイアウトついて開発した。
ー 次世代化：超音波センサーを用いたライン対処

RCJ2025世界大会総合優勝チームの戦術である、ライン際に接近した際に減速しアウトを防ぐ動作を模倣したいと考え
た。彼らに話を聞くと、超音波センサーを用いたと分かった。しかしこのセンサーは制御関数と特性により処理速度が遅
い(50ms安定)、敵を壁と誤検知するというデメリットがあり日本では広まっていない。解決のため、以下制御を行った。
pulseIn()関数のブロッキングを防ぐためSeeed XIAO ESP32S3のFreeRTOS・デュアルコアを用いて10〜15ms
周期で処理を行った。これによりセンサー特有の低速性を軽減した。更に距離変化の傾向から壁とロボット
を判別することで誤検知を抑制し課題を解消した。課題動作と解決後動作は右QRコード先動画にまとめた。
ー ライン検知システムの改良

敵避けをする際、ボールを継続的的に保持する力が課題となった。そこで原因
を補足エリアとして形状選定を行った。fig3~5の３種類について比較を行った。

従来のアナログ検知から、検知時間短縮の為コンパレータを用いたデジタル検知へ変更した。更にセンサ専用のサブマイ
コンを搭載し、処理はベクトル演算による軽量化を行った。以上の結果、処理速度は15ms → 2ms以内に短縮された。
ー センサーレイアウト・間隔の再検討

十字型・エンジェル型・エンジェル十字型が現在の主流レイアウトであるが、それ以上に最短か
つ詳細、連続的にセンサー状況を読み取るため、右fig8のようなレイアウトへとエンジェル十字
型を「拡張」した。また白線を絶えず認識できるよう、センサ間隔の再検討も行った。
以上を実装した結果、実験50回中アウト回数は１５回 →１回 へと劇的な変化となった。

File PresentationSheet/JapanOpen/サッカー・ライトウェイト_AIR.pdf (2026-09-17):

# ー 簡易的に着脱可能なサイドパネル

❶

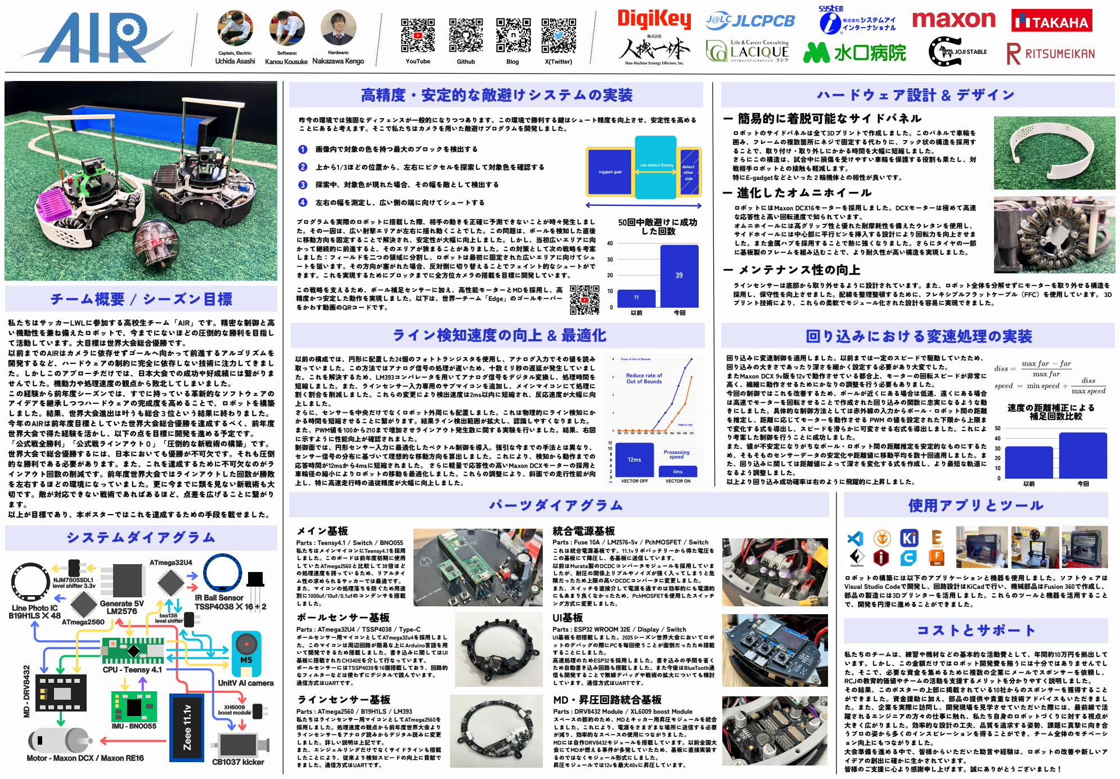
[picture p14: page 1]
50回中敵避けに成功 した回数; CCPPUU -- TTeeeennssyy 44..11; bss138 level shifter; Generate 5V LM2576; AATTmmeeggaa3322UU44; XH6009 boost module; 画像内で対象の色を持つ最大のブロックを検出する; 上から1/3ほどの位置から、左右にピクセルを探索して対象色を確認する; 探索中、対象色が現れた場合、その幅を敵として検出する; 左右の幅を測定し、広い側の端に向けてシュートする; CCaappttaaiinn,, EElleeccttrriicc::; UchidaAsashi; NakazawaKengo; HHaarrddwwaarree::; KanouKousuke; SSooffttwwaarree::; YouTube; Github; Blog; X(Twitter); 速度の距離補正による 補足回数比較; 統合電源基板; メイン基板; Parts : Teensy4.1 / Switch / BNO055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

昨今の環境では強固なディフェンスが一般的になりつつあります。この環境で勝利する鍵はシュート精度を向上させ、安定性を高める
ことにあると考えます。そこで私たちはカメラを用いた敵避けプログラムを開発しました。

ロボットのサイドパネルは全て3Dプリントで作成しました。このパネルで車輪を
囲み、フレームの複数箇所にネジで固定する代わりに、フック状の構造を採用す
ることで、取り付け・取り外しにかかる時間を大幅に短縮しました。
さらにこの構造は、試合中に損傷を受けやすい車輪を保護する役割も果たし、対
戦相手ロボットとの接触も軽減します。
特にE-gadgetなどといった２輪機体との相性が良いです。
ー 進化したオムニホイール

ロボットにはMaxon DCX16モーターを採用しました。DCXモーターは極めて高速
な応答性と高い回転速度で知られています。
オムニホイールには高グリップ性と優れた耐摩耗性を備えたウレタンを使用し、
サイドホイールには中心部に平行ピンを挿入する設計により回転力を向上させま
した。また金属ハブを採用することで熱に強くなりました。さらにタイヤの一部
に基板製のフレームを組み込むことで、より耐久性が高い構造を実現しました。
ー メンテナンス性の向上

プログラムを実際のロボットに搭載した際、相手の動きを正確に予測できないことが時々発生しまし
た。その一因は、広い射撃エリアが左右に揺れ動くことでした。この問題は、ボールを検知した直後
に移動方向を固定することで解決され、安定性が大幅に向上しました。しかし、当初広いエリアに向
かって継続的に前進すると、そのエリアが狭まることがありました。この対策として次の戦略を考案
しました：フィールドを二つの領域に分割し、ロボットは最初に固定された広いエリアに向けてシュ
ートを狙います。その方向が塞がれた場合、反対側に切り替えることでフェイント的なシュートがで
きます。これを実現するためにブロックまでに全方位カメラの搭載を目標に開発しています。

この戦略を支えるため、ボール補足センサーに加え、高性能モーターとMDを採用し、高
精度かつ安定した動作を実現しました。以下は、世界一チーム「Edge」のゴールキーパー
をかわす動画のQRコードです。

ラインセンサーは底部から取り外せるように設計されています。また、ロボット全体を分解せずにモーターを取り外せる構造を
採用し、保守性を向上させました。配線を整理整頓するために、フレキシブルフラットケーブル（FFC）を使用しています。 3D
プリント技術により、これらの柔軟でモジュール化された設計を容易に実現できました。

私たちはサッカーLWLに参加する高校生チーム「AIR」です。精密な制御と高
い機動性を兼ね備えたロボットで、今までにないほどの圧倒的な勝利を目指し
て活動しています。大目標は世界大会総合優勝です。
以前までのAIRはカメラに依存せずゴールへ向かって前進するアルゴリズムを
開発するなど、ハードウェアの制約に完全に依存しない技術に注力してきまし
た。しかしこのアプローチだけでは、日本大会での成功や好成績には繋がりま
せんでした。機動力や処理速度の観点から敗北してしまいました。
この経験から前年度シーズンでは、すでに持っている革新的なソフトウェアの
アイデアを継承しつつハードウェアの完成度を高めることで、ロボットを構築
しました。結果、世界大会進出は叶うも総合３位という結果に終わりました。
今年のAIRは前年度目標としていた世界大会総合優勝を達成するべく、前年度
世界大会で得た経験を活かし、以下の点を目標に開発を進める予定です。
「公式戦全勝利」「公式戦ラインアウト０」「圧倒的な新戦術の構築」です。
世界大会で総合優勝するには、日本においても優勝が不可欠です。それも圧倒
的な勝利である必要があります。また、これを達成するために不可欠なのがラ
インアウト回数の削減です。前年度世界大会ではラインアウトした回数が勝敗
を左右するほどの環境になっていました。更に今までに類を見ない新戦術も大
切です。敵が対応できない戦術であればあるほど、点差を広げることに繋がり
以上が目標であり、本ポスターではこれを達成するための手段を載せました。

回り込みに変速制御を適用しました。以前までは一定のスピードで駆動していたため、
回り込みの大きさであったり深さを細かく設定する必要があり大変でした。
またMaxon DCX 9v版を12vで動作させている都合上、モーターの回転スピードが非常に
高く、繊細に動作させるためにかなりの調整を行う必要もありました。
今回の制御ではこれを改善するため、ボールが近くにある場合は低速、遠くにある場合
は高速でモーターを回転させることで作成された回り込みの関数に忠実になるような動
きにしました。具体的な制御方法としては赤外線の入力からボール・ロボット間の距離
を推定し、距離に応じてモーターを動作させる PWM の値を設定された下限から上限ま
で変化する式を導出し、スピードを滑らかに可変させる右式を導出しました。これによ
り考案した制御を行うことに成功しました。
また、値が不安定になりがちなボール・ロボット間の距離推定を安定的なものにするた
め、そもそものセンサーデータの安定化や距離値に移動平均を数十回適用しました。ま
た、回り込みに関しては距離値によって深さを変化する式を作成し、より最短な軌道に
なるよう調整しました。
以上より回り込み成功確率は右のように飛躍的に上昇しました。

以前の構成では、円形に配置した24個のフォトトランジスタを使用し、アナログ入力でその値を読み
取っていました。この方法ではアナログ信号の処理が遅いため、十数ミリ秒の遅延が発生していまし
た。これを解決するため、LM393コンパレータを用いてアナログ信号をデジタル変換し、処理時間を
短縮しました。また、ラインセンサー入力専用のサブマイコンを追加し、メインマイコンにて処理に
割く割合を削減しました。これらの変更により検出速度は2ms以内に短縮され、反応速度が大幅に向
上しました。
さらに、センサーを中央だけでなくロボット外周にも配置しました。これは物理的にライン検知にか
かる時間を短縮させることに繋がります。結果ライン検出範囲が拡大し、認識しやすくなりました。
また、PWM値を100から210まで増加させラインアウト発生数に関する実験を行いました。結果、右図
に示すように性能向上が確認されました。
制御面では、円形センサー入力に最適化したベクトル制御を導入。強引な今までの手法とは異なり、
センサー信号の分布に基づいて理想的な移動方向を算出しました。これにより、検知から動作までの
応答時間が12msから4msに短縮されました。 さらに軽量で応答性の高いMaxon DCXモーターの採用と
車輪径の縮小によりロボットの移動を最適化しました。これらの調整により、斜面での走行性能が向
上し、特に高速走行時の追従精度が大幅に向上しました。

Parts : Fuse 10A / LM2576-5v / PchMOSFET / Switch
これは統合電源基板です。11.1vリポバッテリーから得た電圧を
この基板にて降圧し、各基板に送信しています。
以前はMurata製のDCDCコンバータモジュールを採用していま
したが、耐圧の関係上リプルやノイズが強く入ってしまうと危
険だったため上限の高いDCDCコンバータに変更しました。
また、スイッチを直接介して電源を通すのは効率的にも電源的
にもあまり良くなかったため、PchMOSFETを使用したスイッチ
ング方式に変更しました。
UI基板

ロボットの構築には以下のアプリケーションと機器を使用しました。ソフトウェアは
Visual Studio Codeで開発し、回路設計はKiCadで行い、機械部品はFusion 360で作成し、
部品の製造には3Dプリンターを活用しました。これらのツールと機器を活用すること
で、開発を円滑に進めることができました。

IR Ball Sensor

Line Photo IC

Parts : ESP32 WROOM 32E / Display / Switch
UI基板を初搭載しました。2025シーズン世界大会においてロボ
ットのデバッグの際にPCを毎回使うことが面倒だったため搭載
することにしました。
高速処理のためESP32を採用しました。書き込みの手間を省く
ため自動書き込み回路も搭載しました。また今後はBlueTooth通
信も開発することで無線デバッグや戦術の拡大についても検討
しています。通信方式はUARTです。
MD・昇圧回路統合基板

私たちのチームは、練習や機材などの基本的な活動費として、年間約10万円を拠出して
います。しかし、この金額だけではロボット開発費を賄うには十分ではありませんでし
た。そこで、必要な資金を集めるために複数の企業にメールでスポンサーを依頼し、
RCJの教育的価値やチームの活動を支援するメリットを分かりやすく説明しました。
その結果、このポスターの上部に掲載されている10社からのスポンサーを獲得すること
ができました。資金援助に加え、部品の提供や貴重な技術アドバイスもいただきまし
た。また、企業を実際に訪問し、開発現場を見学させていただいた際には、最前線で活

UnitV AI camera

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

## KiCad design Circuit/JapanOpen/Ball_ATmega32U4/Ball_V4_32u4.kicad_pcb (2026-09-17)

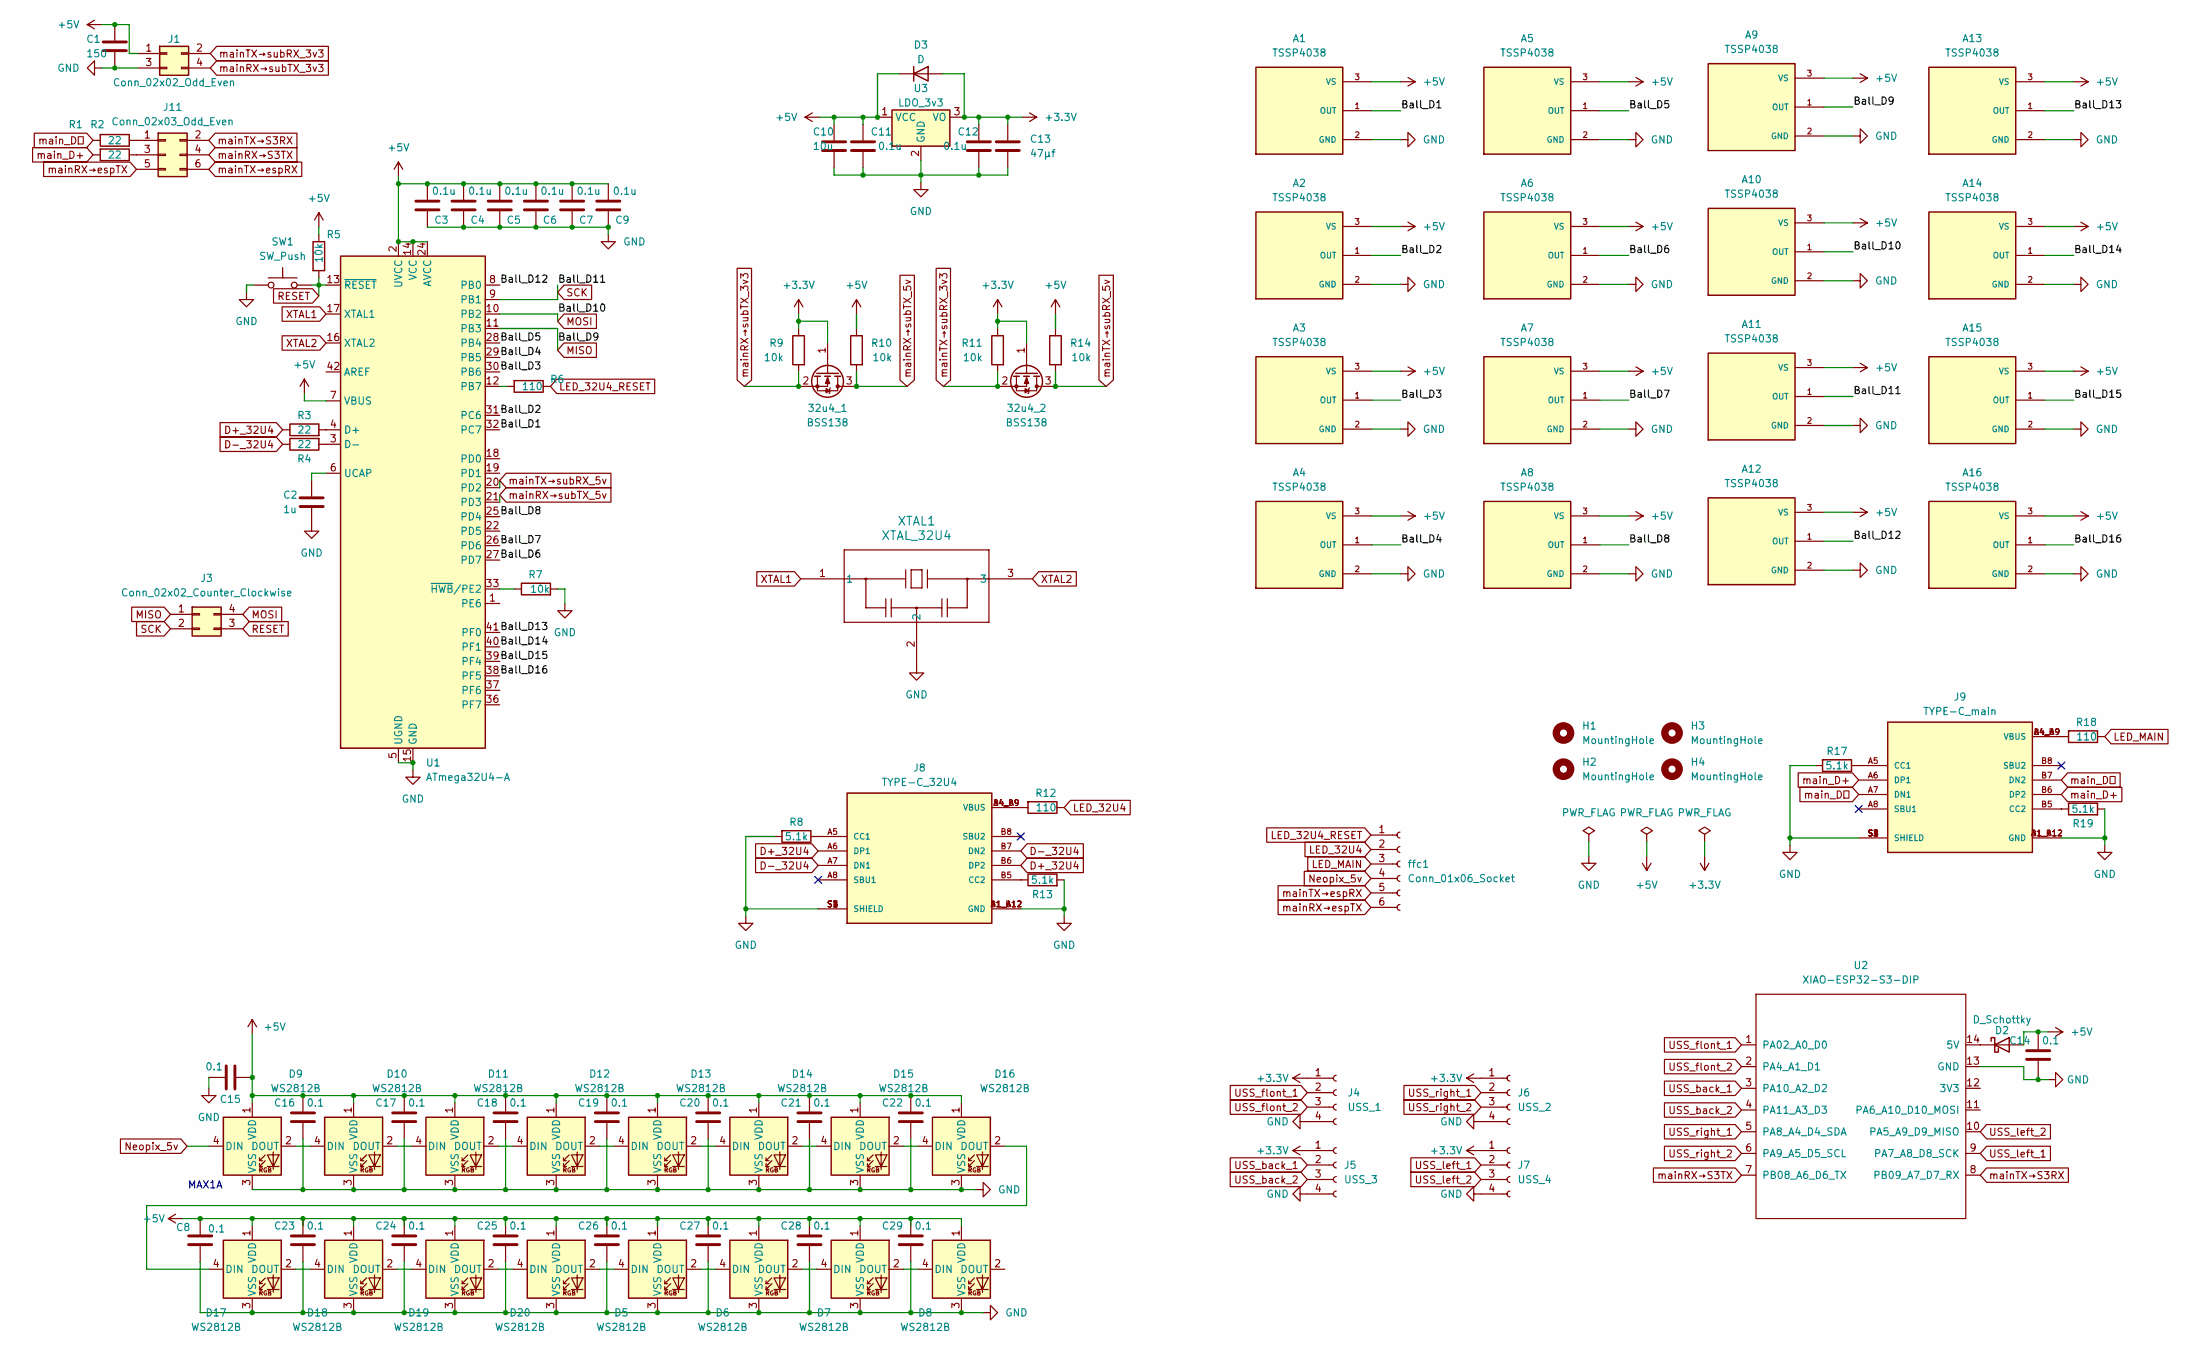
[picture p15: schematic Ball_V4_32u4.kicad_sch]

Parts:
32u4_1, 32u4_2: BSS138; SOT-23; LCSC C192057
A1, A2, A3, A4, A5, A6, A7, A8, A9, A10, A11, A12, A13, A14, A15, A16: TSSP4038; XDCR_TSSP4038; PARTREV 2.3
C1: 150; CP_Radial_D5.0mm_P2.50mm; LCSC C59923
C2: 1u; C_1206_3216Metric; LCSC C1848
C3, C4, C5, C6, C7, C9, C11, C12: 0.1u; C_0603_1608Metric_Pad1.08x0.95mm_HandSolder; LCSC C1581
C8, C14, C16, C17, C18, C19, C20, C21, C22, C23, C24, C25, C26, C27, C28, C29: 0.1; C_0603_1608Metric_Pad1.08x0.95mm_HandSolder; LCSC C1581
C10: 10u; C_0805_2012Metric; LCSC C1713
C13: 47μf; CP_Radial_D5.0mm_P2.00mm
C15: 0.1; C_0603_1608Metric_Pad1.08x0.95mm_HandSolder; LCSC C1848
D2: D_Schottky; D_A-405_P10.16mm_Horizontal
D3: D; D_SOD-123F
D5, D6, D7, D8, D9, D10, D11, D12, D13, D14, D15, D16, D17, D18, D19, D20: WS2812B; LED_WS2812B_PLCC4_5.0x5.0mm_P3.2mm
H1, H2, H3, H4: MountingHole; MountingHole_3.2mm_M3
J1: Conn_02x02_Odd_Even; PinHeader_2x02_P2.54mm_Vertical
J3: Conn_02x02_Counter_Clockwise; PinHeader_2x02_P2.54mm_Vertical
J4: USS_1; PinSocket_1x04_P2.54mm_Vertical
J5: USS_3; PinSocket_1x04_P2.54mm_Vertical
J6: USS_2; PinSocket_1x04_P2.54mm_Vertical
J7: USS_4; PinSocket_1x04_P2.54mm_Vertical
J8: TYPE-C_32U4; NELTRON_5077CR-16SMC2-BK-TR; PARTREV B
J9: TYPE-C_main; NELTRON_5077CR-16SMC2-BK-TR; PARTREV B
J11: Conn_02x03_Odd_Even; PinSocket_2x03_P2.54mm_Vertical
R1, R2, R3, R4: 22; R_1206_3216Metric; LCSC C17958
R5, R7, R9, R10, R11, R14: 10k; R_1206_3216Metric; LCSC C1489
R6, R12, R18: 110; R_1206_3216Metric; LCSC C17909
R8, R13, R17, R19: 5.1k; R_0603_1608Metric_Pad0.98x0.95mm_HandSolder; LCSC C26033
SW1: SW_Push; Switch_SKRPABE010
U1: ATmega32U4-A; TQFP-44_10x10mm_P0.8mm; LCSC C44854
U2: XIAO-ESP32-S3-DIP; XIAO-ESP32-S3-SMD
U3: LDO_3v3; TO-252-2
XTAL1: XTAL_32U4; CSTNE16M0V530000R0_MUR
ffc1: Conn_01x06_Socket; TE_84952-6_1x06-1MP_P1.0mm_Horizontal

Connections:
+3.3V: 32u4_1.1 (G), 32u4_2.1 (G), C12.1, C13.1, D3.2 (A), J4.1, J5.1, J6.1, J7.1, R9.1, R11.1, U3.3 (VO)
+5V: A1.3 (VS), A2.3 (VS), A3.3 (VS), A4.3 (VS), A5.3 (VS), A6.3 (VS), A7.3 (VS), A8.3 (VS), A9.3 (VS), A10.3 (VS), A11.3 (VS), A12.3 (VS), A13.3 (VS), A14.3 (VS), A15.3 (VS), A16.3 (VS), C1.1, C3.2, C4.2, C5.2, C6.2, C7.2, C8.2, C9.2, C10.1, C11.1, C14.2, C15.2, C16.2, C17.2, C18.2, C19.2, C20.2, C21.2, C22.2, C23.2, C24.2, C25.2, C26.2, C27.2, C28.2, C29.2, D2.2 (A), D3.1 (K), D5.1 (VDD), D6.1 (VDD), D7.1 (VDD), D8.1 (VDD), D9.1 (VDD), D10.1 (VDD), D11.1 (VDD), D12.1 (VDD), D13.1 (VDD), D14.1 (VDD), D15.1 (VDD), D16.1 (VDD), D17.1 (VDD), D18.1 (VDD), D19.1 (VDD), D20.1 (VDD), J1.1, R5.1, R10.1, R14.1, U1.2 (UVCC), U1.7 (VBUS), U1.14 (VCC), U1.24 (AVCC), U1.34 (VCC), U1.44 (AVCC), U3.1 (VCC)
/Ball_D1: A1.1 (OUT), U1.32 (PC7)
/Ball_D2: A2.1 (OUT), U1.31 (PC6)
/Ball_D3: A3.1 (OUT), U1.30 (PB6)
/Ball_D4: A4.1 (OUT), U1.29 (PB5)
/Ball_D5: A5.1 (OUT), U1.28 (PB4)
/Ball_D6: A6.1 (OUT), U1.27 (PD7)
/Ball_D7: A7.1 (OUT), U1.26 (PD6)
/Ball_D8: A8.1 (OUT), U1.25 (PD4)
/Ball_D12: A12.1 (OUT), U1.8 (PB0)
/Ball_D13: A13.1 (OUT), U1.41 (PF0)
/Ball_D14: A14.1 (OUT), U1.40 (PF1)
/Ball_D15: A15.1 (OUT), U1.39 (PF4)
/Ball_D16: A16.1 (OUT), U1.38 (PF5)
D+_32U4: J8.A6 (DP1), J8.B6 (DP2), R3.1
D-_32U4: J8.A7 (DN1), J8.B7 (DN2), R4.1
GND: A1.2 (GND), A2.2 (GND), A3.2 (GND), A4.2 (GND), A5.2 (GND), A6.2 (GND), A7.2 (GND), A8.2 (GND), A9.2 (GND), A10.2 (GND), A11.2 (GND), A12.2 (GND), A13.2 (GND), A14.2 (GND), A15.2 (GND), A16.2 (GND), C1.2, C2.2, C3.1, C4.1, C5.1, C6.1, C7.1, C8.1, C9.1, C10.2, C11.2, C12.2, C13.2, C14.1, C15.1, C16.1, C17.1, C18.1, C19.1, C20.1, C21.1, C22.1, C23.1, C24.1, C25.1, C26.1, C27.1, C28.1, C29.1, D5.3 (VSS), D6.3 (VSS), D7.3 (VSS), D8.3 (VSS), D9.3 (VSS), D10.3 (VSS), D11.3 (VSS), D12.3 (VSS), D13.3 (VSS), D14.3 (VSS), D15.3 (VSS), D16.3 (VSS), D17.3 (VSS), D18.3 (VSS), D19.3 (VSS), D20.3 (VSS), J1.3, J4.4, J5.4, J6.4, J7.4, J8.A1_B12 (GND), J8.B1_A12 (GND), J8.S1 (SHIELD), J8.S2 (SHIELD), J8.S3 (SHIELD), J8.S4 (SHIELD), J9.A1_B12 (GND), J9.B1_A12 (GND), J9.S1 (SHIELD), J9.S2 (SHIELD), J9.S3 (SHIELD), J9.S4 (SHIELD), R7.2, R8.2, R13.2, R17.2, R19.2, SW1.2, U1.5 (UGND), U1.15 (GND), U1.23 (GND), U1.35 (GND), U1.43 (GND), U2.13 (GND), U3.2 (GND), XTAL1.2
LED_32U4: R12.1, ffc1.2
LED_32U4_RESET: R6.1, ffc1.1
LED_MAIN: R18.1, ffc1.3
MISO: A9.1 (OUT), J3.1, U1.11 (PB3)
MOSI: A10.1 (OUT), J3.4, U1.10 (PB2)
Neopix_5v: D9.4 (DIN), ffc1.4
unnamed: D2.1 (K), U2.14 (5V)
unnamed: D5.2 (DOUT), D6.4 (DIN)
unnamed: D6.2 (DOUT), D7.4 (DIN)
unnamed: D7.2 (DOUT), D8.4 (DIN)
unnamed: D9.2 (DOUT), D10.4 (DIN)
unnamed: D10.2 (DOUT), D11.4 (DIN)
unnamed: D11.2 (DOUT), D12.4 (DIN)
unnamed: D12.2 (DOUT), D13.4 (DIN)
unnamed: D13.2 (DOUT), D14.4 (DIN)
unnamed: D14.2 (DOUT), D15.4 (DIN)
unnamed: D15.2 (DOUT), D16.4 (DIN)
unnamed: D16.2 (DOUT), D17.4 (DIN)
unnamed: D17.2 (DOUT), D18.4 (DIN)
unnamed: D18.2 (DOUT), D19.4 (DIN)
unnamed: D19.2 (DOUT), D20.4 (DIN)
unnamed: D5.4 (DIN), D20.2 (DOUT)
unnamed: J8.A5 (CC1), R8.1
unnamed: J8.B5 (CC2), R13.1
unnamed: J8.A4_B9 (VBUS), J8.B4_A9 (VBUS), R12.2
unnamed: J9.A5 (CC1), R17.1
unnamed: J9.B5 (CC2), R19.1
unnamed: J9.A4_B9 (VBUS), J9.B4_A9 (VBUS), R18.2
unnamed: J11.1, R1.1
unnamed: J11.3, R2.1
unnamed: R3.2, U1.4 (D+)
unnamed: R4.2, U1.3 (D-)
unnamed: R6.2, U1.12 (PB7)
unnamed: C2.1, U1.6 (UCAP)
unnamed: R7.1, U1.33 (~HWB/PE2)
RESET: J3.3, R5.2, SW1.1, U1.13 (~RESET)
SCK: A11.1 (OUT), J3.2, U1.9 (PB1)
USS_back_1: J5.2, U2.3 (PA10_A2_D2)
USS_back_2: J5.3, U2.4 (PA11_A3_D3)
USS_flont_1: J4.2, U2.1 (PA02_A0_D0)
USS_flont_2: J4.3, U2.2 (PA4_A1_D1)
USS_left_1: J7.2, U2.9 (PA7_A8_D8_SCK)
USS_left_2: J7.3, U2.10 (PA5_A9_D9_MISO)
USS_right_1: J6.2, U2.5 (PA8_A4_D4_SDA)
USS_right_2: J6.3, U2.6 (PA9_A5_D5_SCL)
XTAL1: U1.17 (XTAL1), XTAL1.1
XTAL2: U1.16 (XTAL2), XTAL1.3
mainRX→S3TX: J11.4, U2.7 (PB08_A6_D6_TX)
mainRX→espTX: J11.5, ffc1.6
mainRX→subTX_3v3: 32u4_1.2 (S), J1.4, R9.2
mainRX→subTX_5v: 32u4_1.3 (D), R10.2, U1.21 (PD3)
mainTX→S3RX: J11.2, U2.8 (PB09_A7_D7_RX)
mainTX→espRX: J11.6, ffc1.5
mainTX→subRX_3v3: 32u4_2.2 (S), J1.2, R11.2
mainTX→subRX_5v: 32u4_2.3 (D), R14.2, U1.20 (PD2)
main_D+: J9.A6 (DP1), J9.B6 (DP2), R2.2
main_Dー: J9.A7 (DN1), J9.B7 (DN2), R1.2

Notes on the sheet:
MAX1A

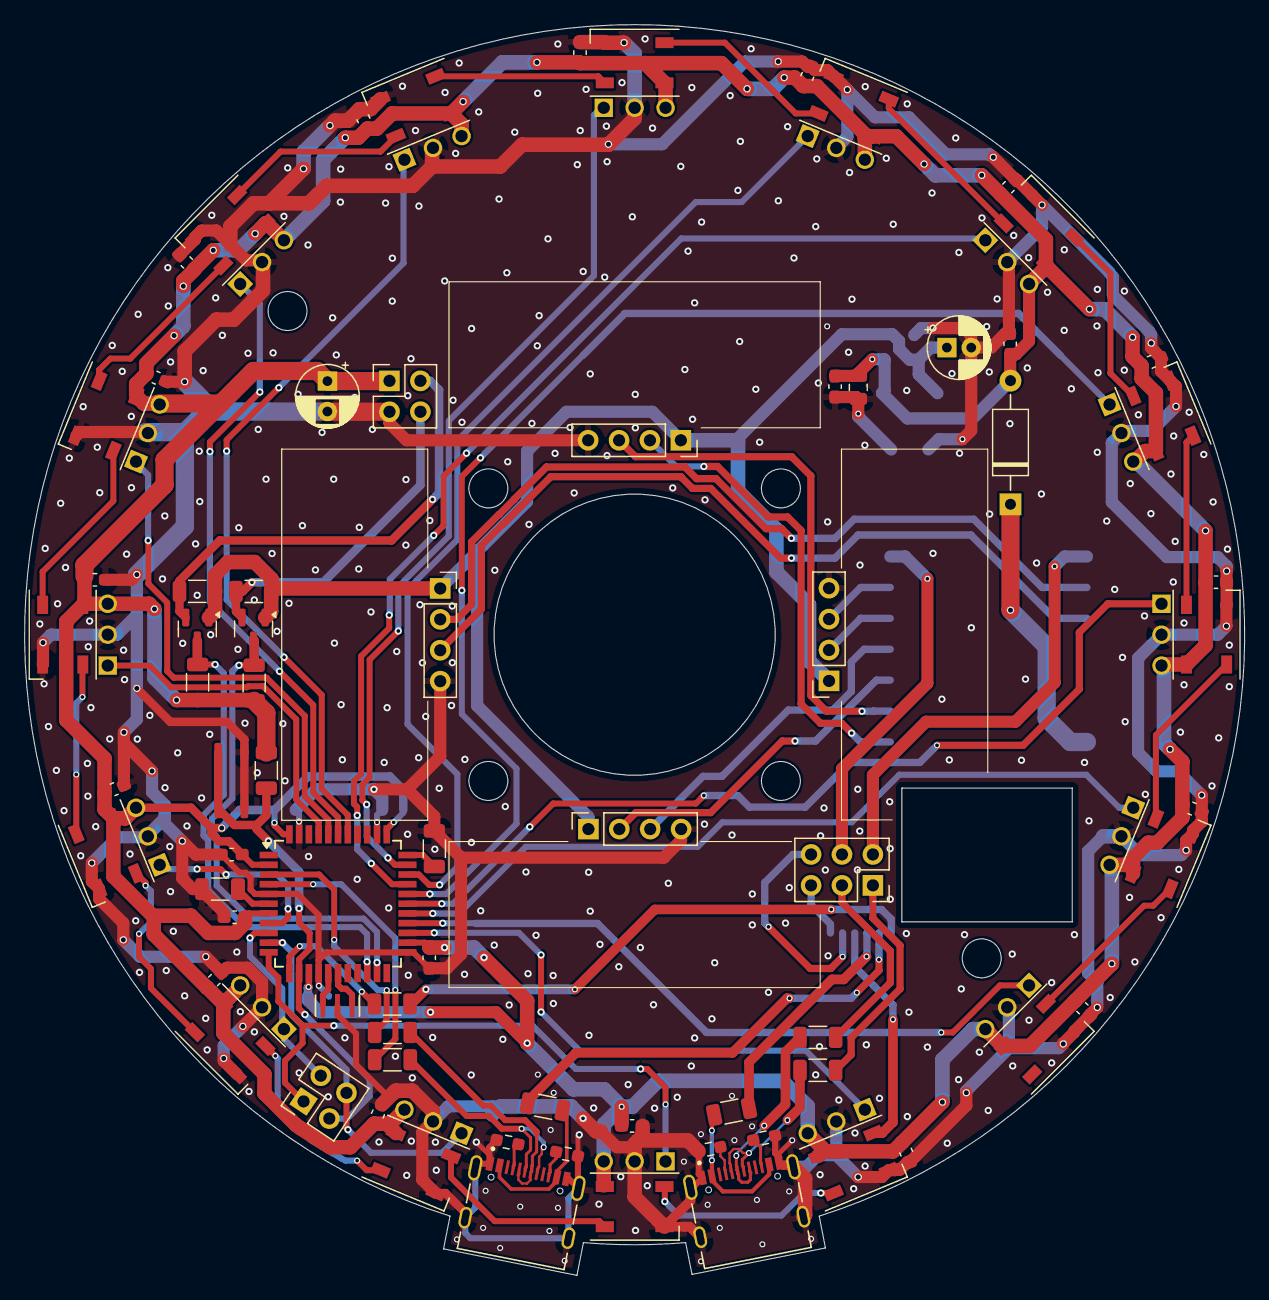
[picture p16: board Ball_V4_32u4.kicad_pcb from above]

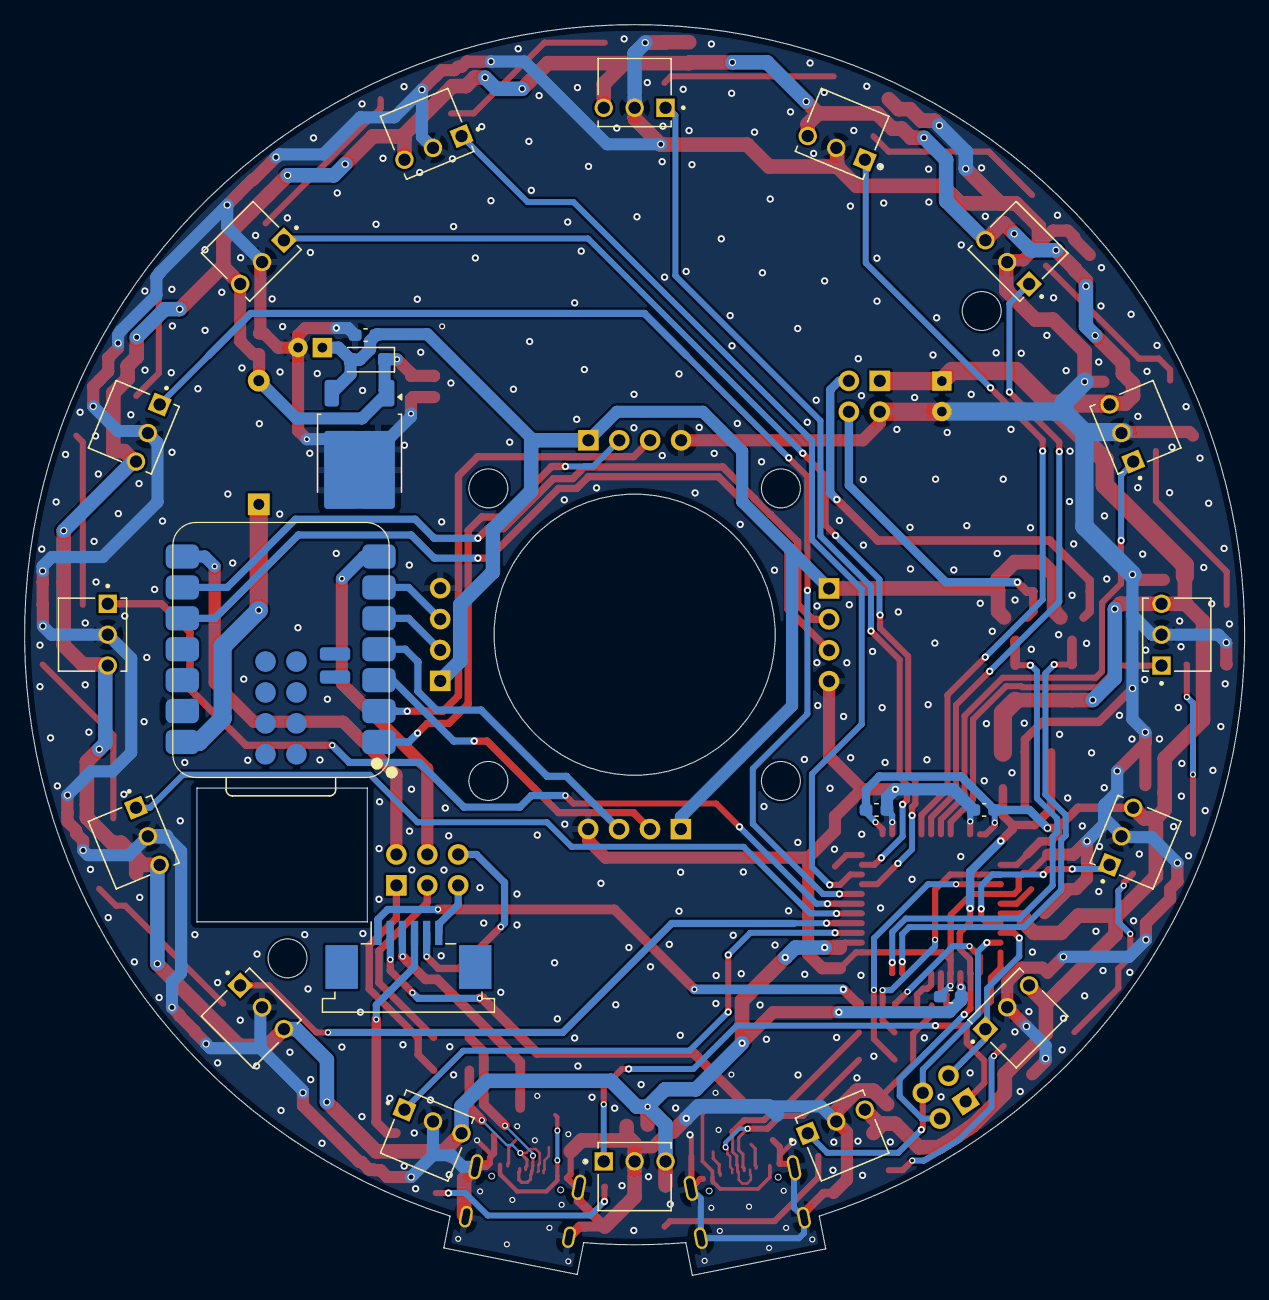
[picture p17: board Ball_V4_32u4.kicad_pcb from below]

Board: 2 copper layers, 100.3 x 102.8 mm, 103 parts (24 on the bottom side), 75 nets.

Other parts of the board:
H5, H5#2: MountingHole; MountingHole_3.2mm_M3

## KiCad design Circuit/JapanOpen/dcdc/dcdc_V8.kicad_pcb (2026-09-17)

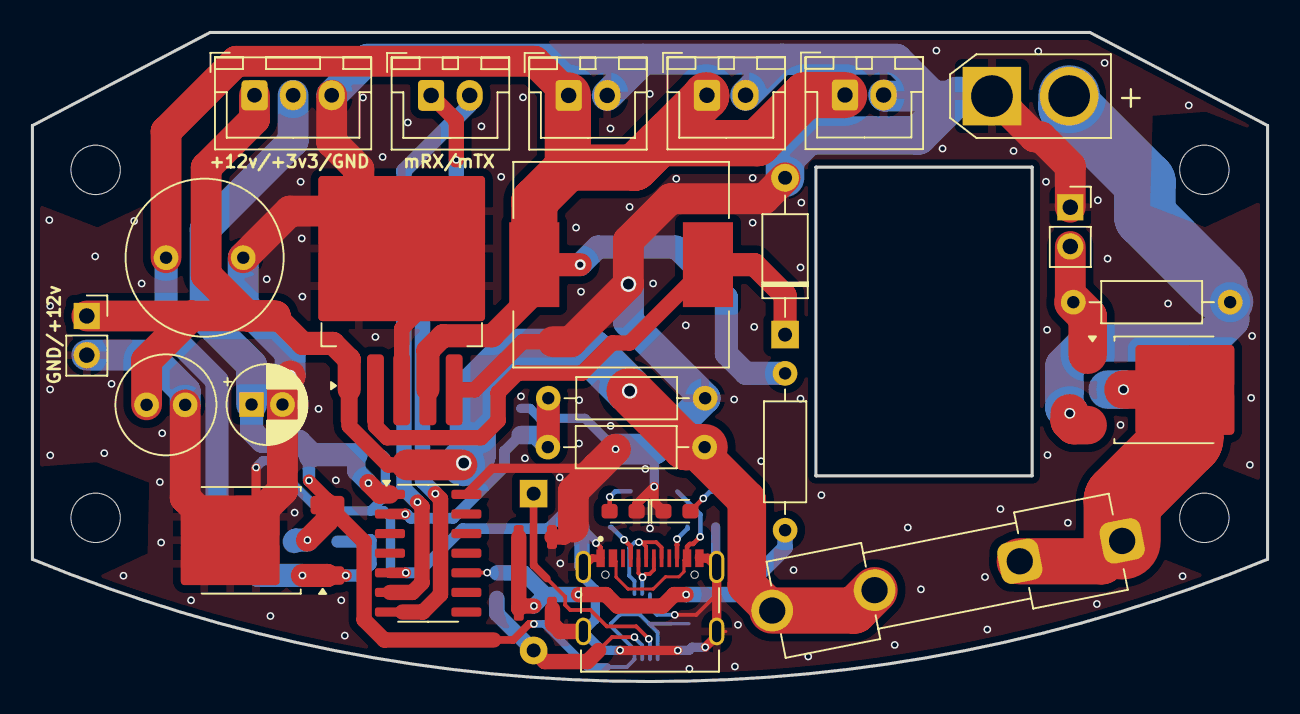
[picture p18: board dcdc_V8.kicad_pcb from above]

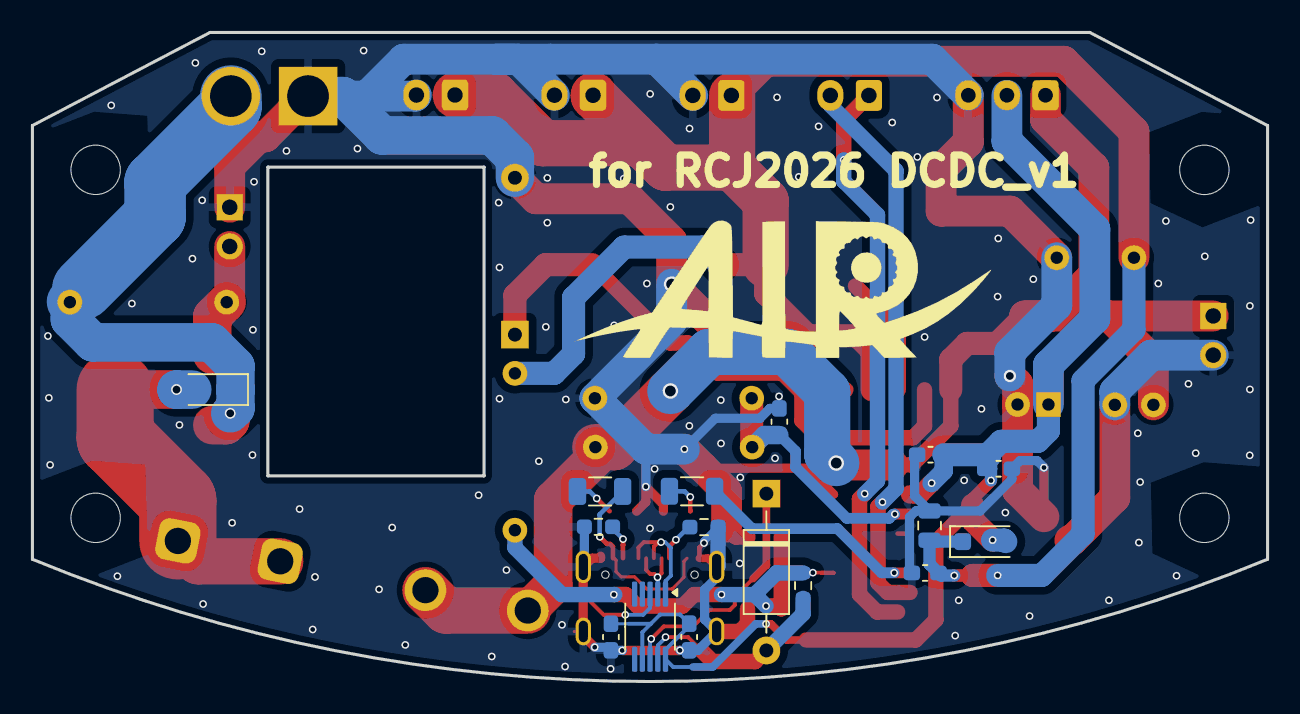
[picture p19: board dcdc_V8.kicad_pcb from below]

Board: 2 copper layers, 80.0 x 42.0 mm, 46 parts (16 on the bottom side), 22 nets.

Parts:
C1: 100u; C_Radial_D6.3mm_H5.0mm_P2.50mm
C2: 1000u; C_Radial_D10.0mm_H12.5mm_P5.00mm
C3, C4, C5, C8: 0.1; C_0603_1608Metric_Pad1.08x0.95mm_HandSolder
C9: 10u; C_0805_2012Metric
C10, C11: 0.1u; C_0603_1608Metric_Pad1.08x0.95mm_HandSolder
C12: 47u; CP_Radial_D5.0mm_P2.00mm
D1, D2: D; D_SOD-123F
D3: RED; LED_0603_1608Metric_Pad1.05x0.95mm_HandSolder
D5: GREEN; LED_0603_1608Metric_Pad1.05x0.95mm_HandSolder
F1: Fuse; Fuseholder_Clip-5x20mm_Keystone_3517_Inline_P23.11x6.76mm_D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
H3, H3#2, H4, H4#2: MountingHole; MountingHole_3.2mm_M3
J1: TYPE-C_ESP32; NELTRON_5077CR-16SMC2-BK-TR
L1: 100u; L_Sunlord_MWSA1204S-1R0
LiPo_1: XT30_IN; AMASS_XT30U-M_1x02_P5.0mm_Vertical
Line_1: Conn_01x02_Socket; JST_XH_B2B-XH-A_1x02_P2.50mm_Vertical
MDR_1: Conn_01x03_Socket; JST_XH_B3B-XH-A_1x03_P2.50mm_Vertical
OLED_1: Conn_01x02_Socket; PinSocket_1x02_P2.54mm_Vertical
Q1: PMOS; TO-252-2
R1, R2, R5: 10k; R_Axial_DIN0207_L6.3mm_D2.5mm_P10.16mm_Horizontal
R3: 4.7k; R_0603_1608Metric
R4: 3.3k; R_Axial_DIN0207_L6.3mm_D2.5mm_P10.16mm_Horizontal
R6, R9: 5.1k; R_0603_1608Metric_Pad0.98x0.95mm_HandSolder
R7: 110; R_1206_3216Metric
R8: 56; R_1206_3216Metric
SBD1: D; D_A-405_P10.16mm_Horizontal
SBD2: SBD; D_A-405_P10.16mm_Horizontal
SW1: SW_SPST; PinSocket_1x02_P2.54mm_Vertical
SW2: SW_Push; Switch_SKRPABE010
U1: LM2576SX-5.0_NOPB; TO-263-5_TabPin6
U2: CH340E; MSOP-10_3x3mm_P0.5mm
U3: LDO_3v3; TO-252-2
U4: ATtiny814-SS; SOIC-14_3.9x8.7mm_P1.27mm
UI_1: Conn_01x02_Socket; JST_XH_B2B-XH-A_1x02_P2.50mm_Vertical
main_psu1: Conn_01x02_Socket; JST_XH_B2B-XH-A_1x02_P2.50mm_Vertical
main_uart1: Conn_01x02_Socket; JST_XH_B2B-XH-A_1x02_P2.50mm_Vertical

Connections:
+3.3V: C3.1, C4.2, C5.2, C11.1, C12.1, D2.2 (A), MDR_1.2, U2.7 (VCC), U2.10 (V3), U3.3 (VO), U4.1 (VCC)
+5V: C2.1, C9.1, C10.1, D2.1 (K), L1.2, Line_1.1, R2.1, U1.4 (FB), U3.1 (VCC), UI_1.1, main_psu1.1
D+: J1.A6 (DP1), J1.B6 (DP2), U2.1 (UD+)
D-: J1.A7 (DN1), J1.B7 (DN2), U2.2 (UD-)
GND: C1.2, C2.2, C3.2, C4.1, C5.1, C8.2, C9.2, C10.2, C11.2, C12.2, D3.1 (K), D5.1 (K), J1.A1_B12 (GND), J1.B1_A12 (GND), J1.S1 (SHIELD), J1.S2 (SHIELD), J1.S3 (SHIELD), J1.S4 (SHIELD), LiPo_1.1 (-), Line_1.2, MDR_1.3, OLED_1.2, R4.2, R6.2, R9.2, SBD1.2 (A), SW1.1 (A), SW2.2, U1.3 (GND), U1.5 (ON/OFF), U1.6 (GND__1), U2.3 (GND), U3.2 (GND), U4.14 (GND), UI_1.2, main_psu1.2
unnamed: D1.2 (A), F1.1, Q1.2 (D)
unnamed: D1.1 (K), LiPo_1.2 (+), Q1.3 (S), R1.1
unnamed: D3.2 (A), R7.1
unnamed: D5.2 (A), R8.1
unnamed: J1.A5 (CC1), R6.1
unnamed: J1.B5 (CC2), R9.1
unnamed: J1.A4_B9 (VBUS), J1.B4_A9 (VBUS), R7.2
unnamed: Q1.1 (G), R1.2, SW1.2 (B)
unnamed: L1.1, SBD1.1 (K), U1.2 (OUT)
unnamed: R3.2, SBD2.2 (A), U2.9 (RXD)
unnamed: SBD2.1 (K), U2.8 (TXD)
unnamed: R8.2, U4.5 (PA7)
UPDI: R2.2, R3.1, SW2.1, U4.10 (~RESET/PA0)
VCC: C1.1, F1.2, MDR_1.1, OLED_1.1, R5.1, U1.1 (VIN)
VOUT: C8.1, R4.1, R5.2, U4.2 (PA4)
mainRX→subTX: U4.7 (PB2), main_uart1.1
mainTX→subRX: U4.6 (PB3), main_uart1.2

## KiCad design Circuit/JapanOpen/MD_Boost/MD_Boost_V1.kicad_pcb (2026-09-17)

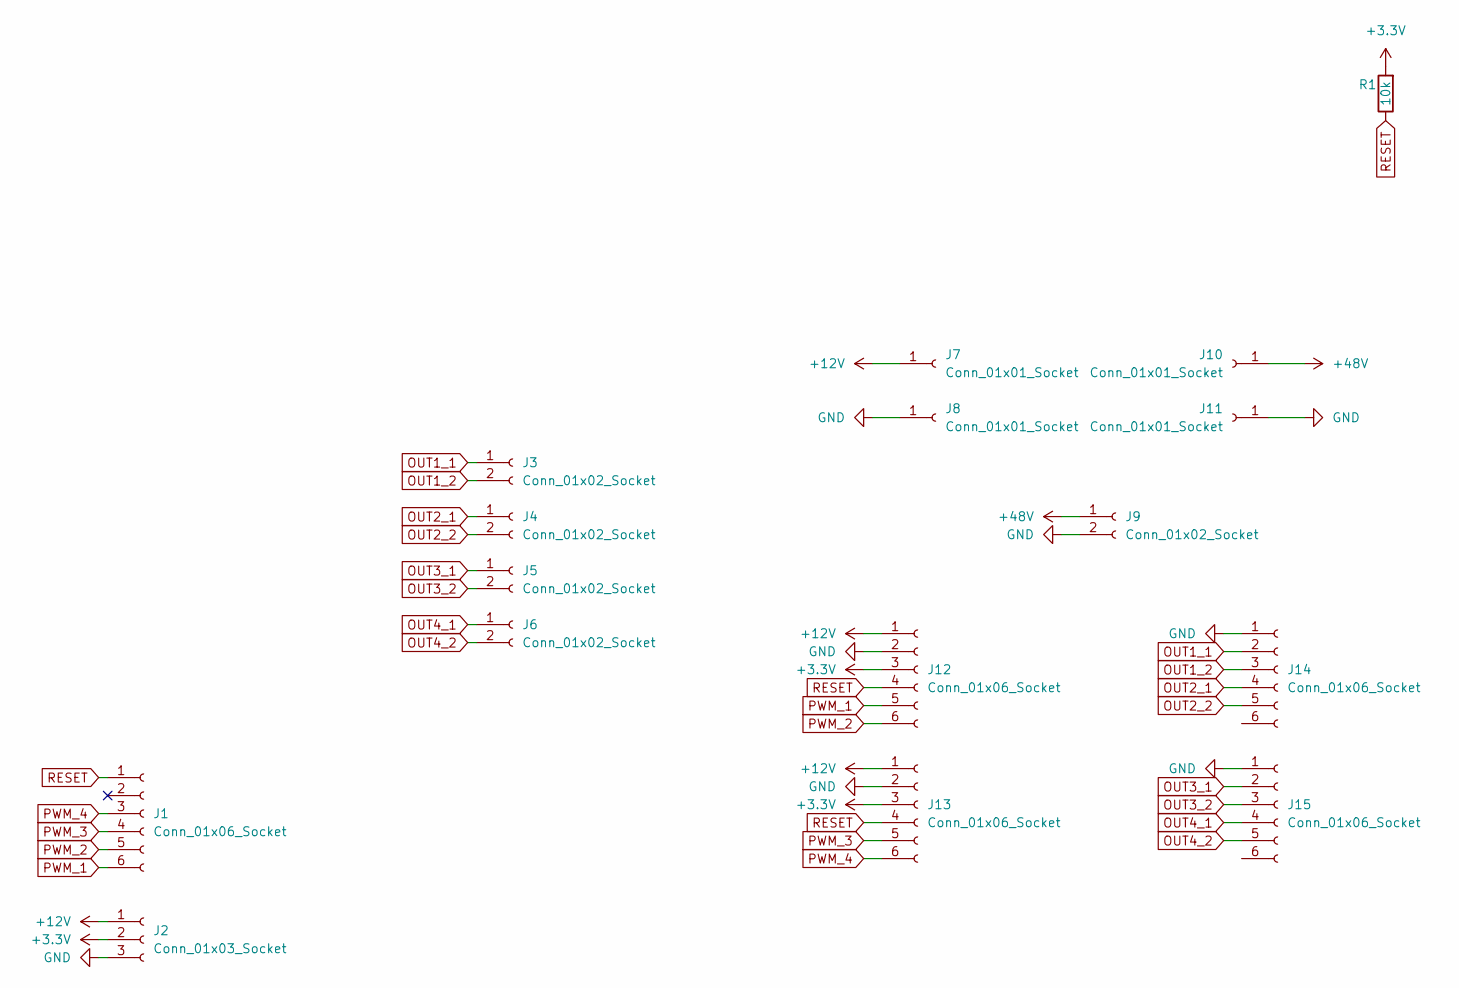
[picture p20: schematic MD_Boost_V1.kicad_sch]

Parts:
J1: Conn_01x06_Socket; TE_84952-6_1x06-1MP_P1.0mm_Horizontal
J2: Conn_01x03_Socket; JST_XH_B3B-XH-AM_1x03_P2.50mm_Vertical
J3, J4, J5, J6: Conn_01x02_Socket; JST_XH_B2B-XH-A_1x02_P2.50mm_Vertical
J7, J8, J10, J11: Conn_01x01_Socket; PinSocket_1x01_P2.54mm_Vertical
J9: Conn_01x02_Socket; JST_XH_B2B-XH-AM_1x02_P2.50mm_Vertical
J12, J13, J14, J15: Conn_01x06_Socket; PinSocket_1x06_P2.54mm_Vertical
R1: 10k; R_Axial_DIN0207_L6.3mm_D2.5mm_P10.16mm_Horizontal; LCSC C15401

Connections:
+3.3V: J2.2, J12.3, J13.3, R1.2
+12V: J2.1, J7.1, J12.1, J13.1
+48V: J9.1, J10.1
GND: J2.3, J8.1, J9.2, J11.1, J12.2, J13.2, J14.1, J15.1
OUT1_1: J3.1, J14.2
OUT1_2: J3.2, J14.3
OUT2_1: J4.1, J14.4
OUT2_2: J4.2, J14.5
OUT3_1: J5.1, J15.2
OUT3_2: J5.2, J15.3
OUT4_1: J6.1, J15.4
OUT4_2: J6.2, J15.5
PWM_1: J1.6, J12.5
PWM_2: J1.5, J12.6
PWM_3: J1.4, J13.5
PWM_4: J1.3, J13.6
RESET: J1.1, J12.4, J13.4, R1.1

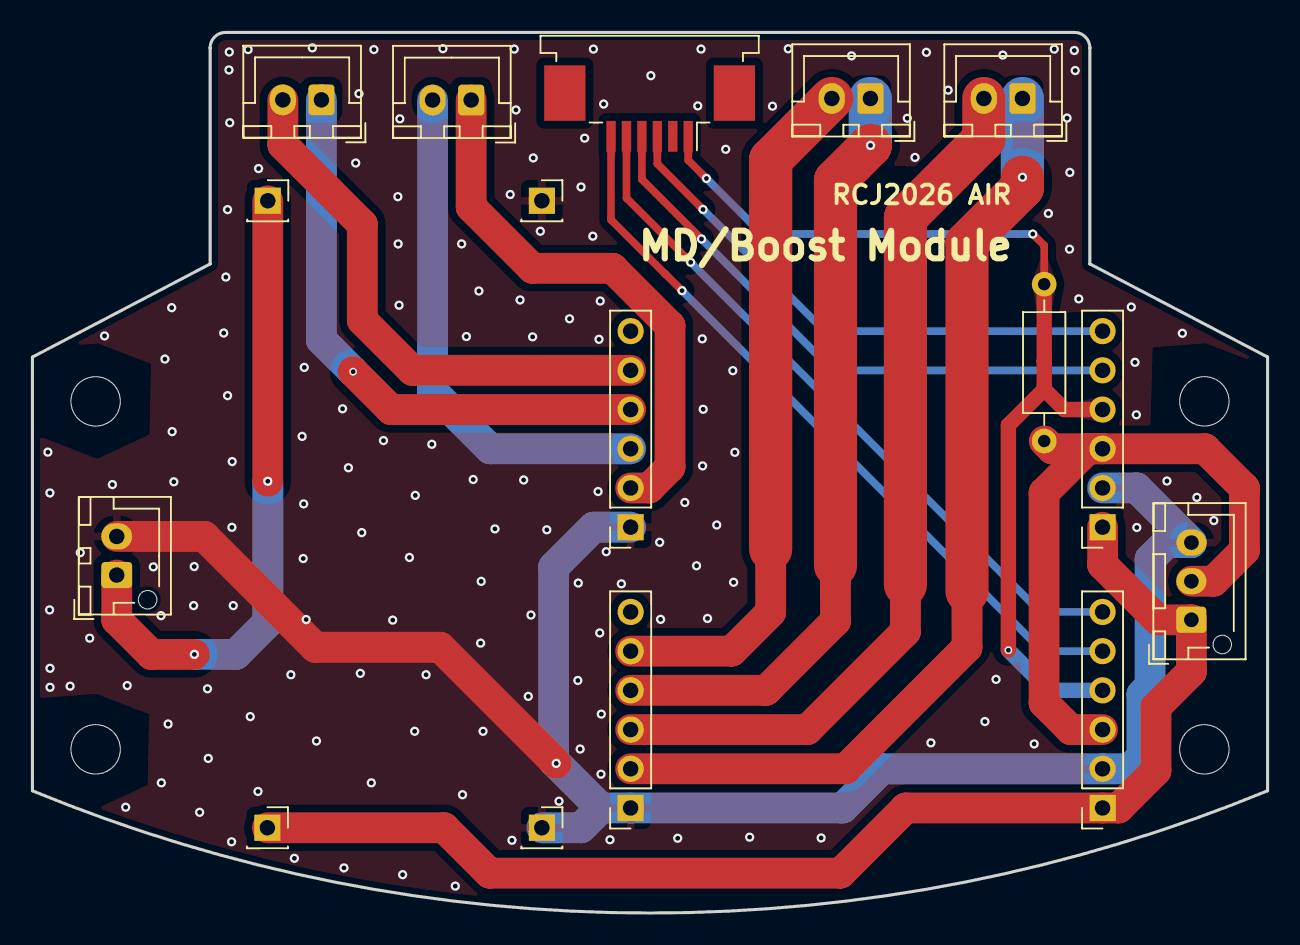
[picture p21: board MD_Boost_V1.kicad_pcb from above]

Board: 2 copper layers, 80.0 x 57.0 mm, 20 parts (0 on the bottom side), 17 nets.

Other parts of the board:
H3, H3#2, H4, H4#2: MountingHole; MountingHole_3.2mm_M3

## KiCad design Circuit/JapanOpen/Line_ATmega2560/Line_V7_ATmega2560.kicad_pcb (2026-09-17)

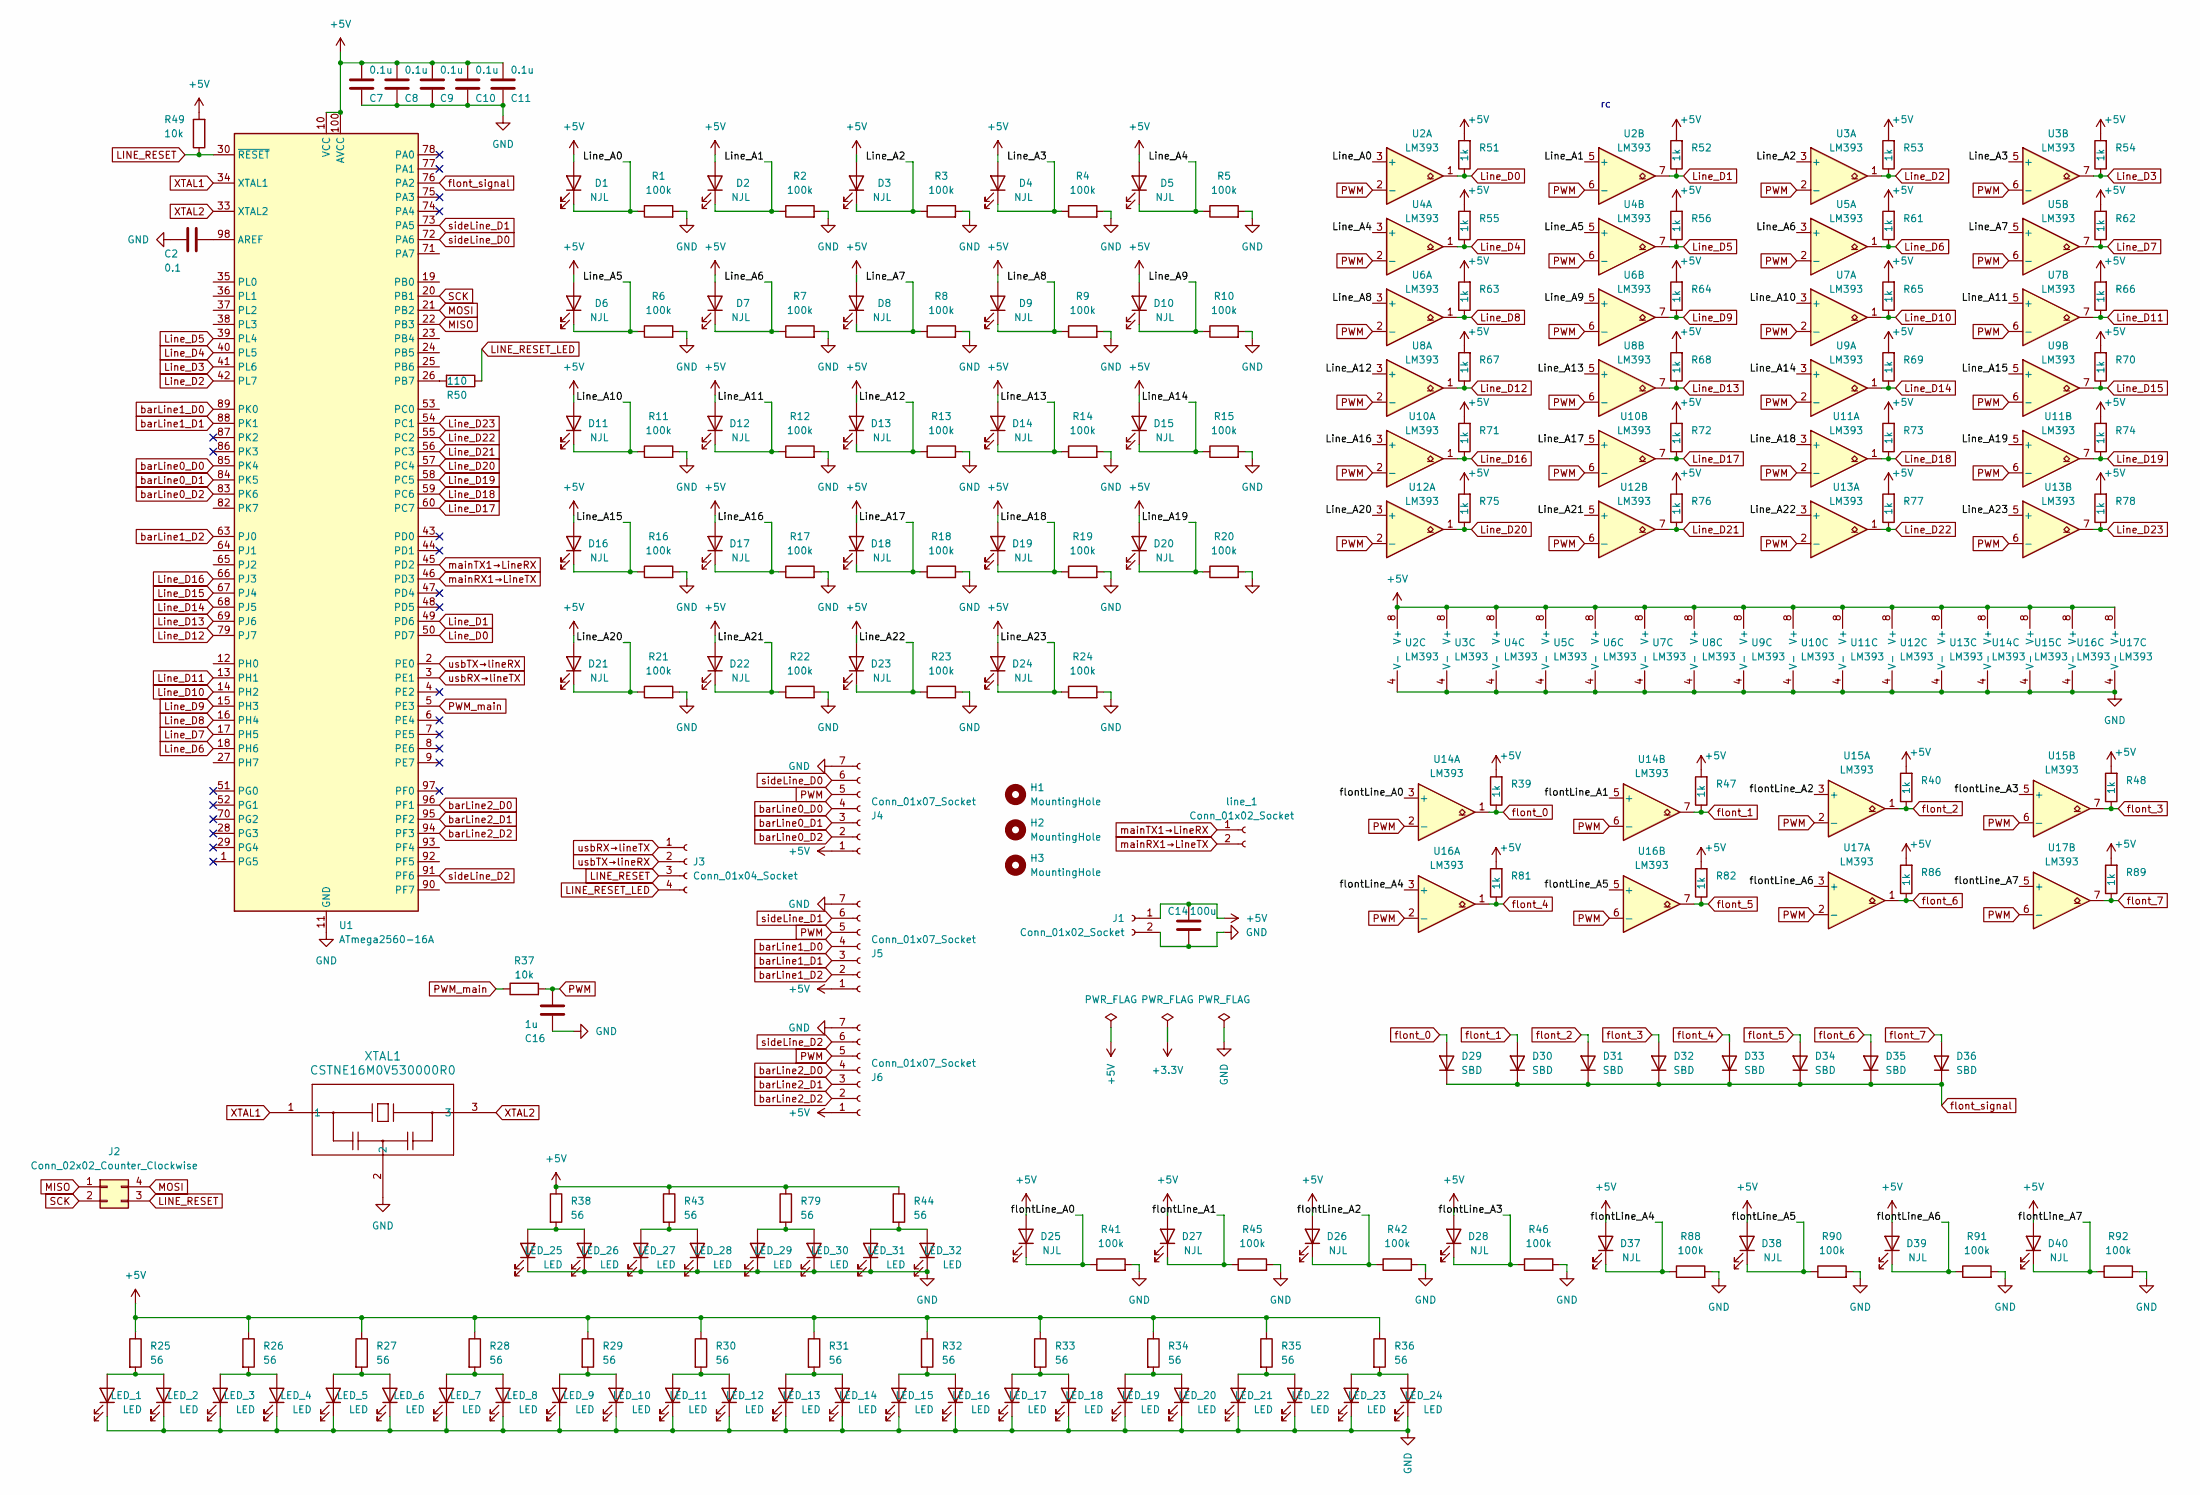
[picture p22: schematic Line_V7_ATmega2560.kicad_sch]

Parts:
C2: 0.1; C_0603_1608Metric_Pad1.08x0.95mm_HandSolder
C7, C8, C9, C10, C11: 0.1u; C_0603_1608Metric_Pad1.08x0.95mm_HandSolder; LCSC C1555
C14: 100u; C_Elec_5x5.4
C16: 1u; C_Elec_4x5.4; LCSC C3348
D1, D2, D3, D4, D5, D6, D7, D8, D9, D10, D11, D12, D13, D14, D15, D16, D17, D18, D19, D20, D21, D22, D23, D24, D25, D26, D27, D28, D37, D38, D39, D40: NJL; LED_0603_1608Metric
D29, D30, D31, D32, D33, D34, D35, D36: SBD; D_SOD-323
H1, H2, H3: MountingHole; MountingHole_3.2mm_M3
J1: Conn_01x02_Socket; JST_XH_S2B-XH-A-1_1x02_P2.50mm_Horizontal
J2: Conn_02x02_Counter_Clockwise; PinHeader_2x02_P2.54mm_Vertical
J3: Conn_01x04_Socket; JST_XH_S4B-XH-A_1x04_P2.50mm_Horizontal
J4, J5, J6: Conn_01x07_Socket; PinSocket_1x07_P2.54mm_Vertical
LED_1, LED_2, LED_3, LED_4, LED_5, LED_6, LED_7, LED_8, LED_9, LED_10, LED_11, LED_12, LED_13, LED_14, LED_15, LED_16, LED_17, LED_18, LED_19, LED_20, LED_21, LED_22, LED_23, LED_24, LED_25, LED_26, LED_27, LED_28, LED_29, LED_30, LED_31, LED_32: LED; LED_0603_1608Metric_Pad1.05x0.95mm_HandSolder
R1, R2, R3, R4, R5, R6, R7, R8, R9, R10, R11, R12, R13, R14, R15, R16, R17, R18, R19, R20, R21, R22, R23, R24, R41, R42, R45, R46, R88, R90, R91, R92: 100k; R_0603_1608Metric; LCSC C23098
R25, R26, R27, R28, R29, R30, R31, R32, R33, R34, R35, R36, R38, R43, R44, R79: 56; R_1206_3216Metric; LCSC C17995
R37, R49: 10k; R_0603_1608Metric; LCSC C23098
R39, R40, R47, R48, R51, R52, R53, R54, R55, R56, R61, R62, R63, R64, R65, R66, R67, R68, R69, R70, R71, R72, R73, R74, R75, R76, R77, R78, R81, R82, R86, R89: 1k; R_0603_1608Metric; LCSC C23098
R50: 110; R_1206_3216Metric; LCSC C17909
U1: ATmega2560-16A; TQFP-100_14x14mm_P0.5mm
U2, U3, U4, U5, U6, U7, U8, U9, U10, U11, U12, U13, U14, U15, U16, U17: LM393; SOIC-8_3.9x4.9mm_P1.27mm
XTAL1: CSTNE16M0V530000R0; CSTNE16M0V530000R0_MUR
line_1: Conn_01x02_Socket; JST_XH_S2B-XH-A-1_1x02_P2.50mm_Horizontal

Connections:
+5V: C7.2, C8.2, C9.2, C10.2, C11.2, C14.1, D1.2 (A), D2.2 (A), D3.2 (A), D4.2 (A), D5.2 (A), D6.2 (A), D7.2 (A), D8.2 (A), D9.2 (A), D10.2 (A), D11.2 (A), D12.2 (A), D13.2 (A), D14.2 (A), D15.2 (A), D16.2 (A), D17.2 (A), D18.2 (A), D19.2 (A), D20.2 (A), D21.2 (A), D22.2 (A), D23.2 (A), D24.2 (A), D25.2 (A), D26.2 (A), D27.2 (A), D28.2 (A), D37.2 (A), D38.2 (A), D39.2 (A), D40.2 (A), J1.1, J4.1, J5.1, J6.1, R25.1, R26.1, R27.1, R28.1, R29.1, R30.1, R31.1, R32.1, R33.1, R34.1, R35.1, R36.1, R38.1, R39.2, R40.2, R43.1, R44.1, R47.2, R48.2, R49.2, R51.2, R52.2, R53.2, R54.2, R55.2, R56.2, R61.2, R62.2, R63.2, R64.2, R65.2, R66.2, R67.2, R68.2, R69.2, R70.2, R71.2, R72.2, R73.2, R74.2, R75.2, R76.2, R77.2, R78.2, R79.1, R81.2, R82.2, R86.2, R89.2, U1.10 (VCC), U1.31 (VCC), U1.61 (VCC), U1.80 (VCC), U1.100 (AVCC), U2.8 (V+), U3.8 (V+), U4.8 (V+), U5.8 (V+), U6.8 (V+), U7.8 (V+), U8.8 (V+), U9.8 (V+), U10.8 (V+), U11.8 (V+), U12.8 (V+), U13.8 (V+), U14.8 (V+), U15.8 (V+), U16.8 (V+), U17.8 (V+); also elsewhere on the board
/Line_A0: D1.1 (K), R1.1, U2.3 (+)
/Line_A1: D2.1 (K), R2.1, U2.5 (+)
/Line_A2: D3.1 (K), R3.1, U3.3 (+)
/Line_A3: D4.1 (K), R4.1, U3.5 (+)
/Line_A4: D5.1 (K), R5.1, U4.3 (+)
/Line_A5: D6.1 (K), R6.1, U4.5 (+)
/Line_A6: D7.1 (K), R7.1, U5.3 (+)
/Line_A7: D8.1 (K), R8.1, U5.5 (+)
/Line_A8: D9.1 (K), R9.1, U6.3 (+)
/Line_A9: D10.1 (K), R10.1, U6.5 (+)
/Line_A10: D11.1 (K), R11.1, U7.3 (+)
/Line_A11: D12.1 (K), R12.1, U7.5 (+)
/Line_A12: D13.1 (K), R13.1, U8.3 (+)
/Line_A13: D14.1 (K), R14.1, U8.5 (+)
/Line_A14: D15.1 (K), R15.1, U9.3 (+)
/Line_A15: D16.1 (K), R16.1, U9.5 (+)
/Line_A16: D17.1 (K), R17.1, U10.3 (+)
/Line_A17: D18.1 (K), R18.1, U10.5 (+)
/Line_A18: D19.1 (K), R19.1, U11.3 (+)
/Line_A19: D20.1 (K), R20.1, U11.5 (+)
/Line_A20: D21.1 (K), R21.1, U12.3 (+)
/Line_A21: D22.1 (K), R22.1, U12.5 (+)
/Line_A22: D23.1 (K), R23.1, U13.3 (+)
/Line_A23: D24.1 (K), R24.1, U13.5 (+)
/flontLine_A0: D25.1 (K), R41.1, U14.3 (+)
/flontLine_A1: D27.1 (K), R45.1, U14.5 (+)
/flontLine_A2: D26.1 (K), R42.1, U15.3 (+)
/flontLine_A3: D28.1 (K), R46.1, U15.5 (+)
/flontLine_A4: D37.1 (K), R88.1, U16.3 (+)
/flontLine_A5: D38.1 (K), R90.1, U16.5 (+)
/flontLine_A6: D39.1 (K), R91.1, U17.3 (+)
/flontLine_A7: D40.1 (K), R92.1, U17.5 (+)
GND: C2.2, C7.1, C8.1, C9.1, C10.1, C11.1, C14.2, C16.2, J1.2, J4.7, J5.7, J6.7, LED_1.1 (K), LED_2.1 (K), LED_3.1 (K), LED_4.1 (K), LED_5.1 (K), LED_6.1 (K), LED_7.1 (K), LED_8.1 (K), LED_9.1 (K), LED_10.1 (K), LED_11.1 (K), LED_12.1 (K), LED_13.1 (K), LED_14.1 (K), LED_15.1 (K), LED_16.1 (K), LED_17.1 (K), LED_18.1 (K), LED_19.1 (K), LED_20.1 (K), LED_21.1 (K), LED_22.1 (K), LED_23.1 (K), LED_24.1 (K), LED_25.1 (K), LED_26.1 (K), LED_27.1 (K), LED_28.1 (K), LED_29.1 (K), LED_30.1 (K), LED_31.1 (K), LED_32.1 (K), R1.2, R2.2, R3.2, R4.2, R5.2, R6.2, R7.2, R8.2, R9.2, R10.2, R11.2, R12.2, R13.2, R14.2, R15.2, R16.2, R17.2, R18.2, R19.2, R20.2, R21.2, R22.2, R23.2, R24.2, R41.2, R42.2, R45.2, R46.2, R88.2, R90.2, R91.2, R92.2, U1.11 (GND), U1.32 (GND), U1.62 (GND), U1.81 (GND), U1.99 (GND), U2.4 (V-), U3.4 (V-), U4.4 (V-), U5.4 (V-), U6.4 (V-), U7.4 (V-), U8.4 (V-), U9.4 (V-), U10.4 (V-), U11.4 (V-), U12.4 (V-), U13.4 (V-), U14.4 (V-), U15.4 (V-), U16.4 (V-), U17.4 (V-), XTAL1.2
LINE_RESET: J2.3, J3.3, R49.1, U1.30 (~RESET)
LINE_RESET_LED: J3.4, R50.1
Line_D0: R51.1, U1.50 (PD7), U2.1
Line_D1: R52.1, U1.49 (PD6), U2.7
Line_D2: R53.1, U1.42 (PL7), U3.1
Line_D3: R54.1, U1.41 (PL6), U3.7
Line_D4: R55.1, U1.40 (PL5), U4.1
Line_D5: R56.1, U1.39 (PL4), U4.7
Line_D6: R61.1, U1.18 (PH6), U5.1
Line_D7: R62.1, U1.17 (PH5), U5.7
Line_D8: R63.1, U1.16 (PH4), U6.1
Line_D9: R64.1, U1.15 (PH3), U6.7
Line_D10: R65.1, U1.14 (PH2), U7.1
Line_D11: R66.1, U1.13 (PH1), U7.7
Line_D12: R67.1, U1.79 (PJ7), U8.1
Line_D13: R68.1, U1.69 (PJ6), U8.7
Line_D14: R69.1, U1.68 (PJ5), U9.1
Line_D15: R70.1, U1.67 (PJ4), U9.7
Line_D16: R71.1, U1.66 (PJ3), U10.1
Line_D17: R72.1, U1.60 (PC7), U10.7
Line_D18: R73.1, U1.59 (PC6), U11.1
Line_D19: R74.1, U1.58 (PC5), U11.7
Line_D20: R75.1, U1.57 (PC4), U12.1
Line_D21: R76.1, U1.56 (PC3), U12.7
Line_D22: R77.1, U1.55 (PC2), U13.1
Line_D23: R78.1, U1.54 (PC1), U13.7
MISO: J2.1, U1.22 (PB3)
MOSI: J2.4, U1.21 (PB2)
unnamed: LED_1.2 (A), LED_2.2 (A), R25.2
unnamed: LED_3.2 (A), LED_4.2 (A), R26.2
unnamed: LED_5.2 (A), LED_6.2 (A), R27.2
unnamed: LED_7.2 (A), LED_8.2 (A), R28.2
unnamed: LED_9.2 (A), LED_10.2 (A), R29.2
unnamed: LED_11.2 (A), LED_12.2 (A), R30.2
unnamed: LED_13.2 (A), LED_14.2 (A), R31.2
unnamed: LED_15.2 (A), LED_16.2 (A), R32.2
unnamed: LED_17.2 (A), LED_18.2 (A), R33.2
unnamed: LED_19.2 (A), LED_20.2 (A), R34.2
unnamed: LED_21.2 (A), LED_22.2 (A), R35.2
unnamed: LED_23.2 (A), LED_24.2 (A), R36.2
unnamed: LED_25.2 (A), LED_26.2 (A), R38.2
unnamed: LED_27.2 (A), LED_28.2 (A), R43.2
unnamed: LED_29.2 (A), LED_30.2 (A), R79.2
unnamed: LED_31.2 (A), LED_32.2 (A), R44.2
unnamed: C2.1, U1.98 (AREF)
unnamed: R50.2, U1.26 (PB7)
PWM: C16.1, J4.5, J5.5, J6.5, R37.2, U2.2 (-), U2.6 (-), U3.2 (-), U3.6 (-), U4.2 (-), U4.6 (-), U5.2 (-), U5.6 (-), U6.2 (-), U6.6 (-), U7.2 (-), U7.6 (-), U8.2 (-), U8.6 (-), U9.2 (-), U9.6 (-), U10.2 (-), U10.6 (-), U11.2 (-), U11.6 (-), U12.2 (-), U12.6 (-), U13.2 (-), U13.6 (-), U14.2 (-), U14.6 (-), U15.2 (-), U15.6 (-), U16.2 (-), U16.6 (-), U17.2 (-), U17.6 (-)
PWM_main: R37.1, U1.5 (PE3)
SCK: J2.2, U1.20 (PB1)
XTAL1: U1.34 (XTAL1), XTAL1.1
XTAL2: U1.33 (XTAL2), XTAL1.3
barLine0_D0: J4.4, U1.85 (PK4)
barLine0_D1: J4.3, U1.84 (PK5)
barLine0_D2: J4.2, U1.83 (PK6)
barLine1_D0: J5.4, U1.89 (PK0)
barLine1_D1: J5.3, U1.88 (PK1)
barLine1_D2: J5.2, U1.63 (PJ0)
barLine2_D0: J6.4, U1.96 (PF1)
barLine2_D1: J6.3, U1.95 (PF2)
barLine2_D2: J6.2, U1.94 (PF3)
flont_0: D29.2 (A), R39.1, U14.1
flont_1: D30.2 (A), R47.1, U14.7; also elsewhere on the board
flont_2: D31.2 (A), R40.1, U15.1; also elsewhere on the board
flont_3: D32.2 (A), R48.1, U15.7; also elsewhere on the board
flont_4: D33.2 (A), R81.1, U16.1; also elsewhere on the board
flont_5: D34.2 (A), R82.1, U16.7; also elsewhere on the board
flont_6: D35.2 (A), R86.1, U17.1
flont_7: D36.2 (A), R89.1, U17.7
flont_signal: D29.1 (K), D30.1 (K), D31.1 (K), D32.1 (K), D33.1 (K), D34.1 (K), D35.1 (K), D36.1 (K), U1.76 (PA2)
mainRX1→LineTX: U1.46 (PD3), line_1.2
mainTX1→LineRX: U1.45 (PD2), line_1.1
sideLine_D0: J4.6, U1.72 (PA6)
sideLine_D1: J5.6, U1.73 (PA5)
sideLine_D2: J6.6, U1.91 (PF6)
usbRX→lineTX: J3.1, U1.3 (PE1)
usbTX→lineRX: J3.2, U1.2 (PE0)

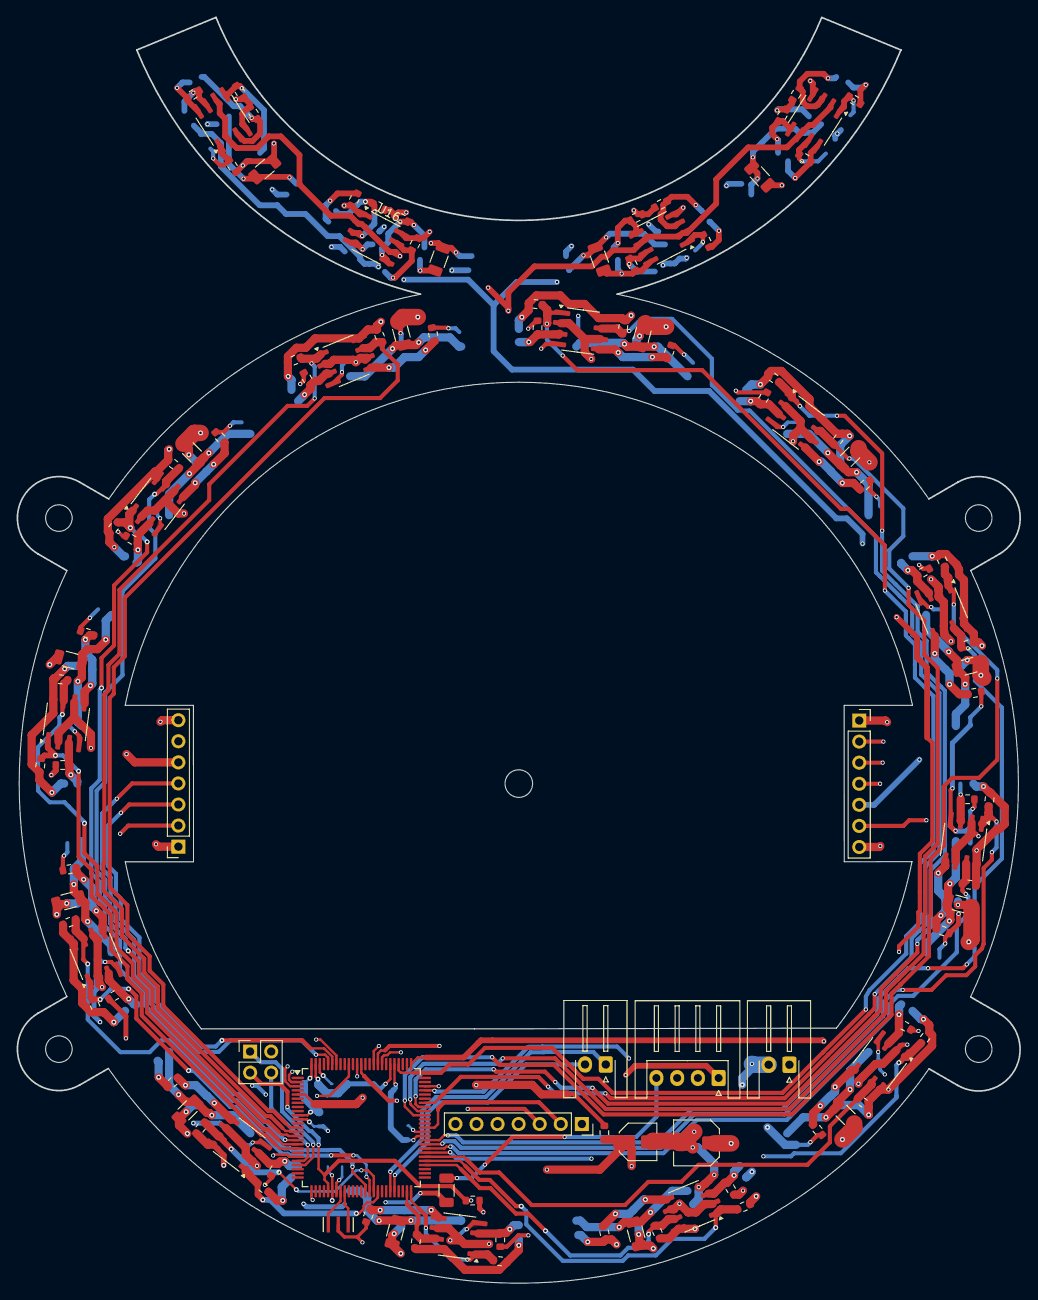
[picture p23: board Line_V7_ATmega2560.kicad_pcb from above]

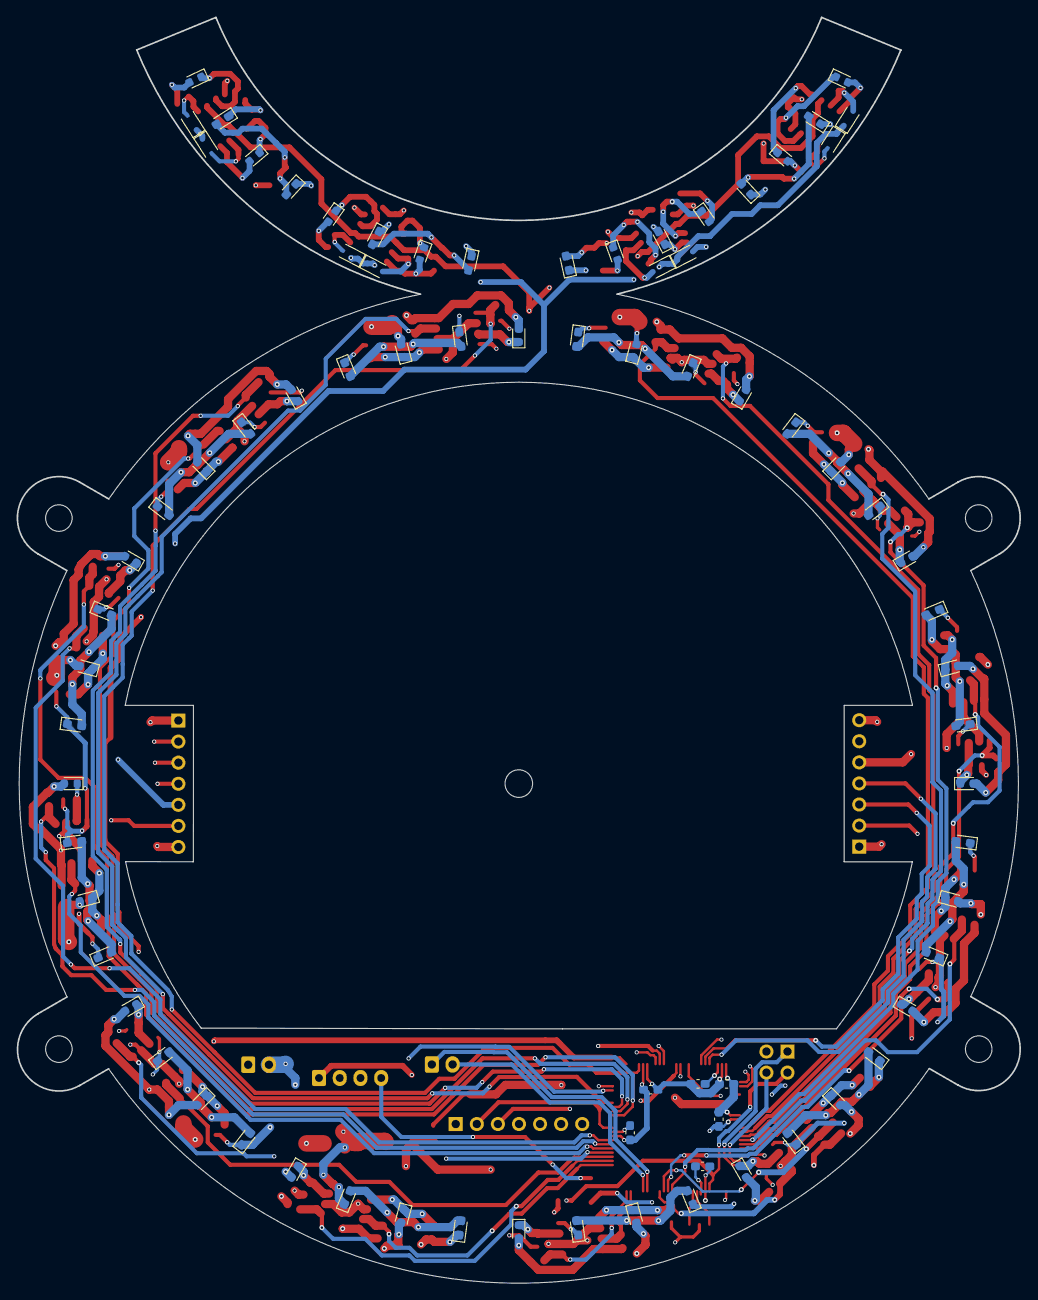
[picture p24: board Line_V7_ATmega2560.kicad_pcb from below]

Board: 4 copper layers, 120.8 x 152.5 mm, 188 parts (78 on the bottom side), 110 nets.

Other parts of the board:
R58, R59, R60, R83, R84: 1k; R_0603_1608Metric

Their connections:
+5V: R58.2, R59.2, R60.2, R83.2, R84.2; also elsewhere on the board
flont_1: R58.1; also elsewhere on the board
flont_2: R59.1; also elsewhere on the board
flont_3: R60.1; also elsewhere on the board
flont_4: R83.1; also elsewhere on the board
flont_5: R84.1; also elsewhere on the board

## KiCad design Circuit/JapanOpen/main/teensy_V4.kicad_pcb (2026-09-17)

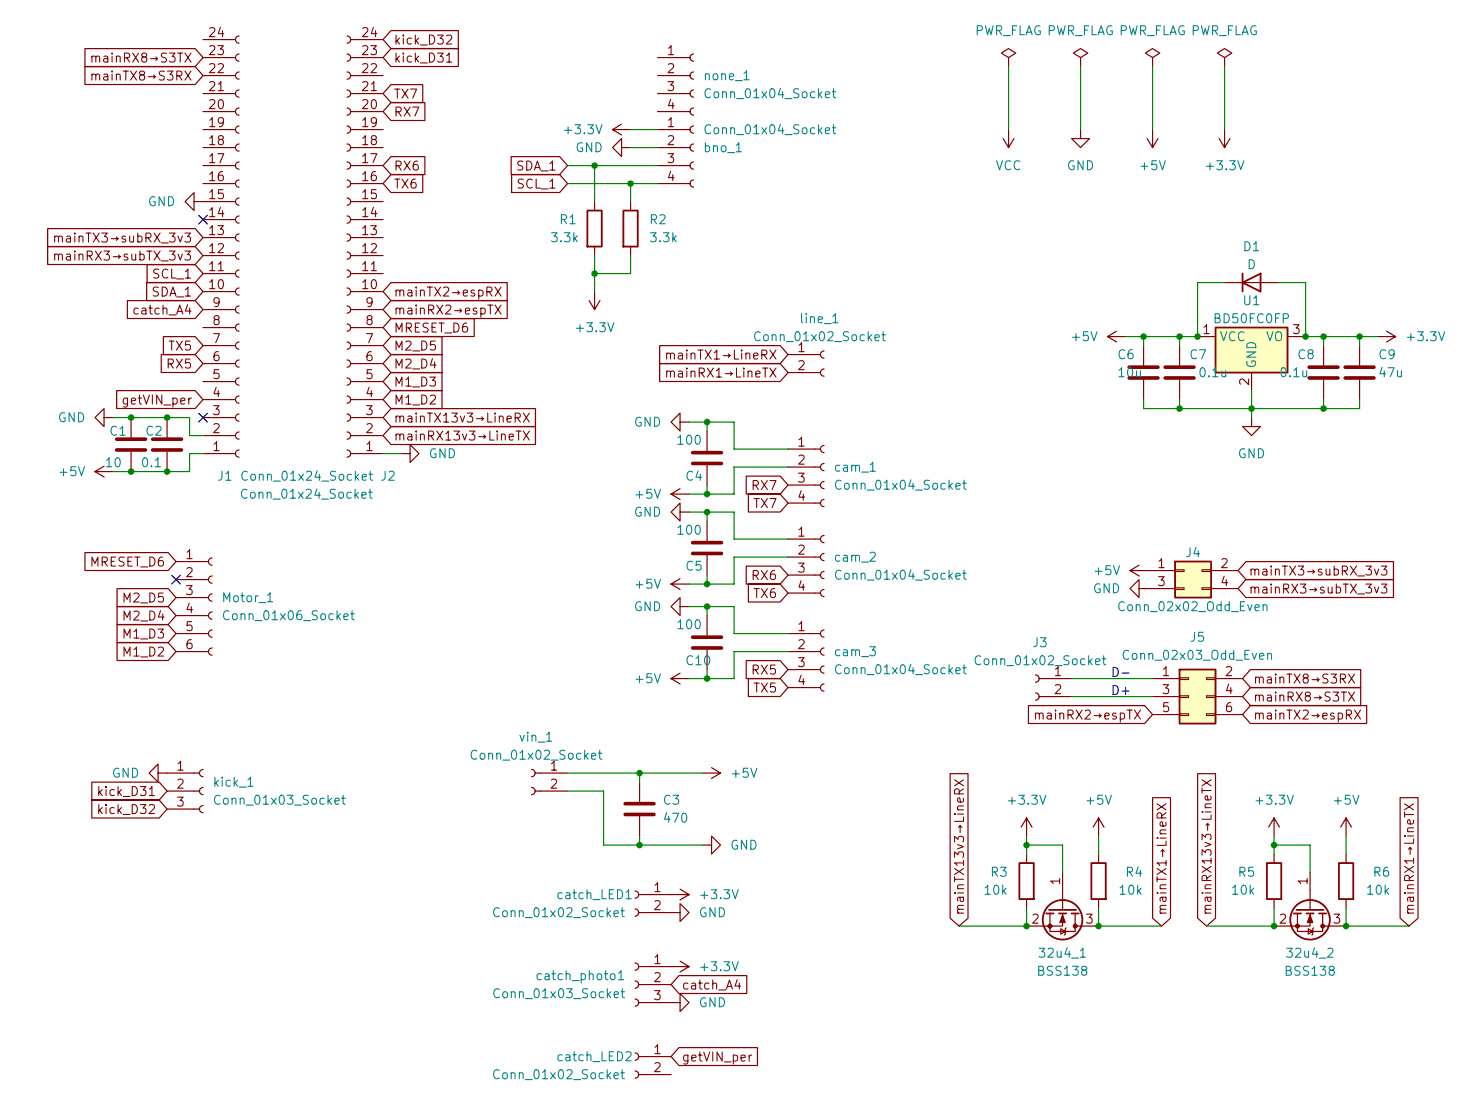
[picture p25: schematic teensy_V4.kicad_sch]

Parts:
32u4_1, 32u4_2: BSS138; SOT-23; LCSC C192057
C1: 10; C_Disc_D5.1mm_W3.2mm_P5.00mm
C2: 0.1; C_Disc_D5.0mm_W2.5mm_P2.50mm
C3: 470; C_Radial_D12.5mm_H20.0mm_P5.00mm
C4, C5, C10: 100; CP_Radial_D5.0mm_P2.00mm
C6: 10u; C_Disc_D5.1mm_W3.2mm_P5.00mm; LCSC C1713
C7, C8: 0.1u; C_Disc_D5.0mm_W2.5mm_P2.50mm; LCSC C1581
C9: 47u; CP_Radial_D5.0mm_P2.00mm; LCSC C3337
D1: D; D_SOD-123F
J1, J2: Conn_01x24_Socket; PinSocket_1x24_P2.54mm_Vertical
J3: Conn_01x02_Socket; PinSocket_1x02_P2.54mm_Vertical
J4: Conn_02x02_Odd_Even; PinHeader_2x02_P2.54mm_Vertical
J5: Conn_02x03_Odd_Even; PinSocket_2x03_P2.54mm_Vertical
Motor_1: Conn_01x06_Socket; TE_84952-6_1x06-1MP_P1.0mm_Horizontal
R1: 3.3k; R_Axial_DIN0207_L6.3mm_D2.5mm_P10.16mm_Horizontal
R2: 3.3k; R_Axial_DIN0207_L6.3mm_D2.5mm_P10.16mm_Horizontal; LCSC C22978
R3, R4, R5, R6: 10k; R_1206_3216Metric_Pad1.30x1.75mm_HandSolder; LCSC C1489
U1: BD50FC0FP; TO-252-2
bno_1: Conn_01x04_Socket; PinSocket_1x04_P2.54mm_Vertical
cam_1, cam_2, cam_3: Conn_01x04_Socket; JST_XH_B4B-XH-A_1x04_P2.50mm_Vertical
catch_LED1, catch_LED2: Conn_01x02_Socket; JST_XH_B2B-XH-A_1x02_P2.50mm_Vertical
catch_photo1: Conn_01x03_Socket; JST_XH_B3B-XH-A_1x03_P2.50mm_Vertical
kick_1: Conn_01x03_Socket; JST_XH_B3B-XH-A_1x03_P2.50mm_Vertical
line_1: Conn_01x02_Socket; JST_XH_B2B-XH-A_1x02_P2.50mm_Vertical
none_1: Conn_01x04_Socket; PinSocket_1x04_P2.54mm_Vertical
vin_1: Conn_01x02_Socket; JST_XH_B2B-XH-A_1x02_P2.50mm_Vertical

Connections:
+3.3V: 32u4_1.1 (G), 32u4_2.1 (G), C8.1, C9.1, D1.2 (A), R1.2, R2.2, R3.1, R5.1, U1.3 (VO), bno_1.1, catch_LED1.1, catch_photo1.1
+5V: C1.2, C2.2, C3.1, C4.1, C5.1, C6.1, C7.1, C10.1, D1.1 (K), J1.1, J4.1, R4.1, R6.1, U1.1 (VCC), cam_1.2, cam_2.2, cam_3.2, vin_1.1
GND: C1.1, C2.1, C3.2, C4.2, C5.2, C6.2, C7.2, C8.2, C9.2, C10.2, J1.2, J1.15, J2.1, J4.3, U1.2 (GND), bno_1.2, cam_1.1, cam_2.1, cam_3.1, catch_LED1.2, catch_photo1.3, kick_1.1, vin_1.2
M1_D2: J2.4, Motor_1.6
M1_D3: J2.5, Motor_1.5
M2_D4: J2.6, Motor_1.4
M2_D5: J2.7, Motor_1.3
MRESET_D6: J2.8, Motor_1.1
unnamed: J3.1, J5.1
unnamed: J3.2, J5.3
RX5: J1.6, cam_3.3
RX6: J2.17, cam_2.3
RX7: J2.20, cam_1.3
SCL_1: J1.11, R2.1, bno_1.4
SDA_1: J1.10, R1.1, bno_1.3
TX5: J1.7, cam_3.4
TX6: J2.16, cam_2.4
TX7: J2.21, cam_1.4
catch_A4: J1.9, catch_photo1.2
getVIN_per: J1.4, catch_LED2.1
kick_D31: J2.23, kick_1.2
kick_D32: J2.24, kick_1.3
mainRX1→LineTX: 32u4_2.3 (D), R6.2, line_1.2
mainRX2→espTX: J2.9, J5.5
mainRX3→subTX_3v3: J1.12, J4.4
mainRX8→S3TX: J1.23, J5.4
mainRX13v3→LineTX: 32u4_2.2 (S), J2.2, R5.2
mainTX1→LineRX: 32u4_1.3 (D), R4.2, line_1.1
mainTX2→espRX: J2.10, J5.6
mainTX3→subRX_3v3: J1.13, J4.2
mainTX8→S3RX: J1.22, J5.2
mainTX13v3→LineRX: 32u4_1.2 (S), J2.3, R3.2

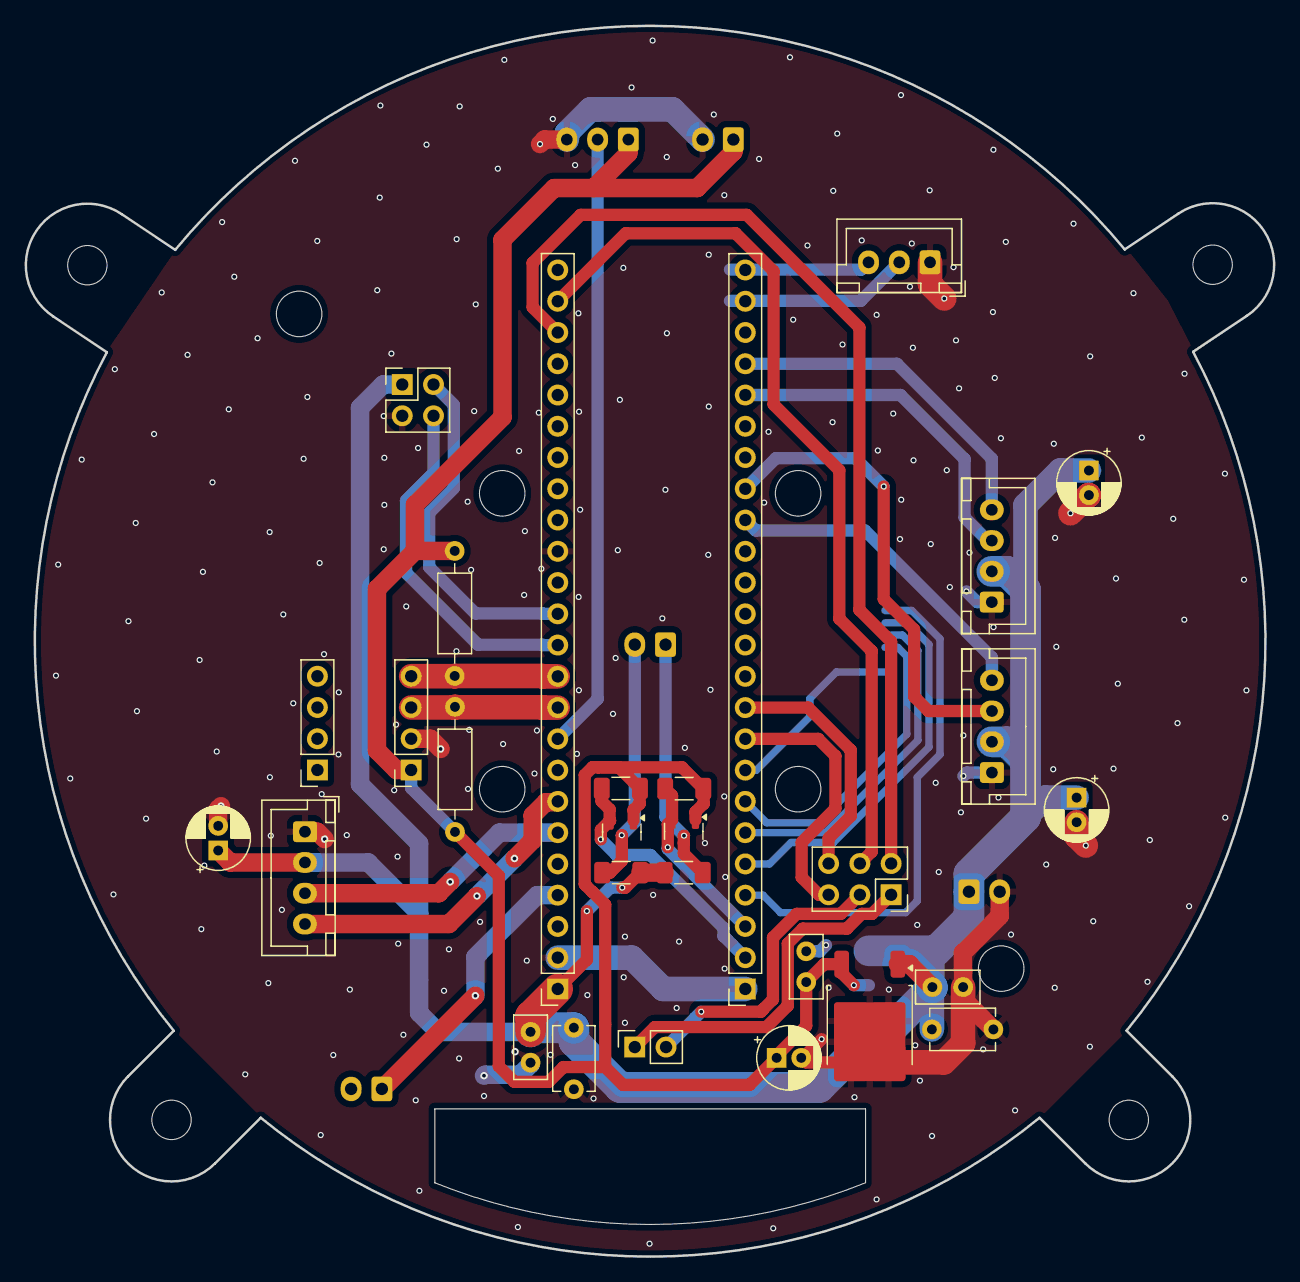
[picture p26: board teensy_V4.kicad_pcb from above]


Board: 2 copper layers, 101.4 x 100.0 mm, 40 parts (7 on the bottom side), 32 nets.

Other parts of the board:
H1, H2, H3, H4: MountingHole; MountingHole_3.2mm_M3

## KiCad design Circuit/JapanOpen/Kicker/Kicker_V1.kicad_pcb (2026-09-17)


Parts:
C1, C2: 3300; C_Radial_D18.0mm_H35.5mm_P7.50mm
D1: SBD; D_SOD-323_HandSoldering
D2, D3: D; D_SOD-123F
H1, H2: MountingHole; MountingHole_3.2mm_M3
K1: AQW212EHA; SMDIP-8_W7.62mm
LED_D1: LED; LED_0603_1608Metric_Pad1.05x0.95mm_HandSolder
Q1: PMOS; TO-252-2
Q2: NMOS; TO-220-3_Horizontal_TabDown
R2: 68; R_1206_3216Metric
R3: 1.6k; R_1206_3216Metric; LCSC C4908
R4: 1k; R_2512_6332Metric; LCSC C31884
R5: 3.3k; R_2512_6332Metric; LCSC C1469
R6: 150; R_2512_6332Metric; LCSC C25471
R7: 3k; R_2512_6332Metric; LCSC C2934109
R8: 1.6k; R_1206_3216Metric; LCSC C102100
R9: 10k; R_1206_3216Metric
main_1, main_2: Conn_01x03_Socket; JST_XH_B3B-XH-A_1x03_P2.50mm_Vertical
sole2: Conn_01x02_Socket; JST_XH_B2B-XH-A_1x02_P2.50mm_Vertical

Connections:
+12V: K1.5, main_2.1
+48V: D1.2 (A), main_2.3
GND: C1.2, C2.2, K1.7, LED_D1.1 (K), Q2.3 (S), R9.1, main_2.2
GND_MAIN: K1.2, K1.4, main_1.3
unnamed: D1.1 (K), D2.1 (K), Q1.3 (S), R4.1
unnamed: D2.2 (A), Q1.2 (D), R6.1
unnamed: D3.2 (A), Q2.1 (D), sole2.2
unnamed: C1.1, C2.1, D3.1 (K), R6.2, R7.1, sole2.1
unnamed: K1.1, R3.2
unnamed: K1.3, R8.2
unnamed: K1.6, R2.1
unnamed: K1.8, R5.1
unnamed: LED_D1.2 (A), R7.2
unnamed: Q1.1 (G), R4.2, R5.2
unnamed: Q2.2 (G), R2.2, R9.2
kick_1: R3.1, main_1.1
kick_2: R8.1, main_1.2



Board: 4 copper layers, 73.1 x 30.3 mm, 22 parts (11 on the bottom side), 17 nets.

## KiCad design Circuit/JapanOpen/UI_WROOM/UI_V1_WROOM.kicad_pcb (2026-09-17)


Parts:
BZ1: Buzzer; XDCR_KXG0909P
C1, C3, C4, C5, C6, C8, C9, C11, C12: 0.1u; C_0603_1608Metric_Pad1.08x0.95mm_HandSolder; LCSC C1581
C2: 0.1; C_0603_1608Metric_Pad1.08x0.95mm_HandSolder; LCSC C1581
C7: 10u; C_Disc_D5.1mm_W3.2mm_P5.00mm; LCSC C1713
C10: 47u; CP_Radial_D5.0mm_P2.00mm; LCSC C3337
D1: GREEN; LED_0603_1608Metric_Pad1.05x0.95mm_HandSolder
D2, D4, D5, D6, D7, D8: RED; LED_0603_1608Metric_Pad1.05x0.95mm_HandSolder
D3: D; D_SOD-123F
J1: TYPE-C_Line; NELTRON_5077CR-16SMC2-BK-TR; PARTREV B
J2: TYPE-C_ESP32; NELTRON_5077CR-16SMC2-BK-TR; PARTREV B
J3: Conn_01x02_Socket; JST_XH_B2B-XH-A_1x02_P2.50mm_Vertical
J4: Conn_01x04_Socket; PinSocket_1x04_P2.54mm_Vertical
J5: Conn_01x04_Socket; JST_XH_S4B-XH-A_1x04_P2.50mm_Horizontal
R1: 10k; R_1206_3216Metric; LCSC C26033
R2: 1k; R_Axial_DIN0207_L6.3mm_D2.5mm_P10.16mm_Horizontal
R3: 56; R_1206_3216Metric; LCSC C17909
R4, R6, R9, R11: 5.1k; R_0603_1608Metric_Pad0.98x0.95mm_HandSolder; LCSC C26033
R5, R10: 110; R_1206_3216Metric; LCSC C17909
R7, R8: 10k; R_1206_3216Metric; LCSC C1489
SW1, SW2, SW3: SW_Push; Switch_SKRPABE010
U1: ESP32-WROOM-32
U2: CH340K; SSOP-10-1EP_3.9x4.9mm_P1mm_EP2.1x3.3mm
U3: UMH3N; UMT6
U4: BD50FC0FP; TO-252-2
U5: CH340E; MSOP-10_3x3mm_P0.5mm
ffc1: Conn_01x06_Socket; TE_84952-6_1x06-1MP_P1.0mm_Horizontal
neopix1: BSS138; SOT-23; LCSC C192057
tact_1, tact_2, tact_3: SW_Push; SW_PUSH-12mm
toggle_1: SW_SPDT; PinSocket_1x03_P2.54mm_Vertical

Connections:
32u4_reset: D6.2 (A), ffc1.6
32u4_vbus: D4.2 (A), ffc1.5
+3.3V: C2.1, C3.2, C5.1, C9.1, C10.1, D3.2 (A), J4.2, R1.1, R2.1, R7.1, U1.2 (VDD), U2.7 (VCC), U4.3 (VO), neopix1.1 (G)
+5V: C7.1, C8.1, C11.1, D3.1 (K), J3.1, R8.1, U4.1 (VCC), U5.7 (VCC)
BUZZER: BZ1.1 (+), BZ1.P, U1.16 (IO13)
D+_ESP: J2.A6 (DP1), J2.B6 (DP2), U2.1 (UD+)
D+_LINE: J1.A6 (DP1), J1.B6 (DP2), U5.1 (UD+)
D-_ESP: J2.A7 (DN1), J2.B7 (DN2), U2.2 (UD-)
D-_LINE: J1.A7 (DN1), J1.B7 (DN2), U5.2 (UD-)
DTR: U2.4 (~DTR), U3.2, U3.4
ESP_EN: C1.1, R1.2, SW1.1, U1.3 (EN), U3.6
ESP_IO0: C4.1, SW2.1, U1.25 (IO0), U3.3
GND: BZ1.2 (-), BZ1.N, C1.2, C2.2, C3.1, C4.2, C5.2, C6.1, C7.2, C8.2, C9.2, C10.2, C11.2, C12.2, D1.1 (K), D2.1 (K), D4.1 (K), D5.1 (K), D6.1 (K), D7.1 (K), D8.1 (K), J1.A1_B12 (GND), J1.B1_A12 (GND), J1.S1 (SHIELD), J1.S2 (SHIELD), J1.S3 (SHIELD), J1.S4 (SHIELD), J2.A1_B12 (GND), J2.B1_A12 (GND), J2.S1 (SHIELD), J2.S2 (SHIELD), J2.S3 (SHIELD), J2.S4 (SHIELD), J3.2, J4.1, R4.2, R6.2, R9.2, R11.2, SW1.2, SW2.2, SW3.2, U1.1 (GND), U1.15 (GND), U1.38 (GND), U1.39 (GND), U2.3 (GND), U2.11 (GND), U4.2 (GND), U5.3 (GND), tact_1.2, tact_2.2, tact_3.2, toggle_1.2 (B)
LINE_RESET: J5.3, SW3.1
LINE_RESET_LED: D7.2 (A), J5.4
Neopix: R7.2, U1.31 (IO19), neopix1.2 (S)
Neopix_5v: R8.2, ffc1.3, neopix1.3 (D)
unnamed: D1.2 (A), R3.1
unnamed: D2.2 (A), R5.1
unnamed: D8.2 (A), R10.1
unnamed: J1.A5 (CC1), R9.1
unnamed: J1.B5 (CC2), R11.1
unnamed: J1.A4_B9 (VBUS), J1.B4_A9 (VBUS), R10.2
unnamed: J2.A5 (CC1), R4.1
unnamed: J2.B5 (CC2), R6.1
unnamed: J2.A4_B9 (VBUS), J2.B4_A9 (VBUS), R5.2
unnamed: R3.2, U1.26 (IO4)
unnamed: C6.2, U2.10 (V3)
unnamed: C12.1, U5.10 (V3)
RTS: U2.6 (~RTS), U3.1, U3.5
RX→TX_ESP: U1.35 (TXD0/IO1), U2.9 (RXD)
SCL_OLED: J4.3, U1.36 (IO22)
SDA_OLED: J4.4, U1.33 (IO21)
TX→RX_ESP: U1.34 (RXD0/IO3), U2.8 (TXD)
mainRX→espTX: U1.28 (IO17), ffc1.1
mainTX→espRX: U1.27 (IO16), ffc1.2
main_vbus: D5.2 (A), ffc1.4
tact_1: U1.10 (IO25), tact_1.1
tact_2: U1.11 (IO26), tact_2.1
tact_3: U1.12 (IO27), tact_3.1
togg: R2.2, U1.37 (IO23), toggle_1.1 (A)
usbRX→lineTX: J5.1, U5.9 (RXD)
usbTX→lineRX: J5.2, U5.8 (TXD)



Board: 2 copper layers, 80.0 x 49.0 mm, 51 parts (24 on the bottom side), 43 nets.

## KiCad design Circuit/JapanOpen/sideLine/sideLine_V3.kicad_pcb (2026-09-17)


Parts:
D1, D2, D3, D4, D5, D8, D11, D14, D18, D19, D20: NJL; LED_0603_1608Metric
D6, D7, D9, D10, D12, D13, D15, D16: SBD; D_SOD-323
J1: Conn_01x07_Socket; PinSocket_1x07_P2.54mm_Vertical
LED_1, LED_2, LED_3, LED_4, LED_5, LED_6, LED_7, LED_8, LED_9, LED_10, LED_11, LED_12: LED; LED_0603_1608Metric_Pad1.05x0.95mm_HandSolder
R1, R3, R5, R7, R9, R13: 56; R_1206_3216Metric; LCSC C17995
R2, R4, R6, R8, R12, R15, R19, R20, R21, R25, R26: 100k; R_0603_1608Metric; LCSC C23098
R10, R11, R17, R18, R23, R24, R27, R28, R29, R30, R31: 1k; R_0603_1608Metric; LCSC C23098
U1, U2, U3, U4, U5, U6: LM393; SOIC-8_3.9x4.9mm_P1.27mm

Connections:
+5V: D1.2 (A), D2.2 (A), D3.2 (A), D4.2 (A), D5.2 (A), D8.2 (A), D11.2 (A), D14.2 (A), D18.2 (A), D19.2 (A), D20.2 (A), J1.1, R1.1, R3.1, R5.1, R7.1, R9.1, R10.2, R11.2, R13.1, R17.2, R18.2, R23.2, R24.2, R27.2, R28.2, R29.2, R30.2, R31.2, U1.8 (V+), U2.8 (V+), U3.8 (V+), U4.8 (V+), U5.8 (V+), U6.8 (V+)
/A2: D18.1 (K), R19.1, U5.5 (+)
/A3: D19.1 (K), R21.1, U6.3 (+)
/A4: D20.1 (K), R26.1, U6.5 (+)
/flontLine_A0: D1.1 (K), R2.1, U1.3 (+)
/flontLine_A1: D2.1 (K), R4.1, U1.5 (+)
/flontLine_A2: D3.1 (K), R6.1, U3.3 (+)
/flontLine_A3: D4.1 (K), R8.1, U3.5 (+)
/flontLine_A4: D5.1 (K), R12.1, U2.3 (+)
/flontLine_A5: D8.1 (K), R15.1, U2.5 (+)
/flontLine_A6: D11.1 (K), R20.1, U4.3 (+)
/flontLine_A7: D14.1 (K), R25.1, U4.5 (+)
GND: J1.7, LED_1.1 (K), LED_2.1 (K), LED_3.1 (K), LED_4.1 (K), LED_5.1 (K), LED_6.1 (K), LED_7.1 (K), LED_8.1 (K), LED_9.1 (K), LED_10.1 (K), LED_11.1 (K), LED_12.1 (K), R2.2, R4.2, R6.2, R8.2, R12.2, R15.2, R19.2, R20.2, R21.2, R25.2, R26.2, U1.4 (V-), U2.4 (V-), U3.4 (V-), U4.4 (V-), U5.4 (V-), U6.4 (V-)
unnamed: LED_1.2 (A), LED_2.2 (A), R1.2
unnamed: LED_3.2 (A), LED_4.2 (A), R3.2
unnamed: LED_5.2 (A), LED_6.2 (A), R5.2
unnamed: LED_7.2 (A), LED_8.2 (A), R7.2
unnamed: LED_9.2 (A), LED_10.2 (A), R9.2
unnamed: LED_11.2 (A), LED_12.2 (A), R13.2
PWM: J1.5, U1.2 (-), U1.6 (-), U2.2 (-), U2.6 (-), U3.2 (-), U3.6 (-), U4.2 (-), U4.6 (-), U5.6 (-), U6.2 (-), U6.6 (-)
barLine0_D1: J1.4, R29.1, U5.7
barLine0_D2: J1.3, R30.1, U6.1
barLine0_D3: J1.2, R31.1, U6.7
flont_0: D6.2 (A), R10.1, U1.1
flont_1: D7.2 (A), R17.1, U1.7
flont_2: D9.2 (A), R23.1, U3.1
flont_3: D10.2 (A), R27.1, U3.7
flont_4: D12.2 (A), R11.1, U2.1
flont_5: D13.2 (A), R18.1, U2.7
flont_6: D15.2 (A), R24.1, U4.1
flont_7: D16.2 (A), R28.1, U4.7
flont_signal: D6.1 (K), D7.1 (K), D9.1 (K), D10.1 (K), D12.1 (K), D13.1 (K), D15.1 (K), D16.1 (K), J1.6



Board: 4 copper layers, 37.5 x 84.2 mm, 66 parts (23 on the bottom side), 32 nets.

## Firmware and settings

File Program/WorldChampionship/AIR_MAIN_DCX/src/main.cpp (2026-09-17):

#include <Arduino.h>
#include <LINE_test.h>
#include <MOTOR.h>
#include <BNOPID.h>
#include <MA.h>
#include <BALL.h>
#include <KICK.h>
#include "UI.h"
#include "USS.h"
#include "Defence.h"
#include "Attack.h"
#include <ESCControl.h>

BALL ball;
BNOPID bnopid;
SIMPLIFY simplify;
MOTOR motor;
LINE_TEST line_test;
KICK kick;
Cam cam; 
UI ui;
USS uss;
Defence defence;
Attack attack;
const int escPin = 3;
const int comm = 37;
const int comm2 = 38;
const int comm3 = 39;
ESCControl esc(escPin);
//スイッチ
int isToggle_ON = 0;
int selected_role = 0;
int kick_request = 0;  
int robot_start = 0;
const int motor_pin = 2;
uint32_t lastResetCause = 0;

void checkResetCause() {
  // 起動直後のレジスタ値をコピー
  lastResetCause = SRC_SRSR;

  // レジスタをクリア（次のリセットに備える）
  SRC_SRSR = lastResetCause;

  // 原因に応じたログ出力や安全対策
  if (lastResetCause & (1 << 4)) {
    // 【重要】ウォッチドッグが原因なら、何か異常があった証拠
    // ここでモーター出力を強制停止するなどの安全処理を入れる
    Serial.println("ALERT: Recovered from Watchdog Reset!");
  } else if (lastResetCause & (1 << 0)) {
    Serial.println("Normal Power-on.");
  }
}

//First.

void setup()
{
  delay(500);
  Serial.begin(9600);
  if(CrashReport){
    Serial.println(CrashReport);
  }

  checkResetCause();
  line_test.begin(921600);
  ball.begin(921600);
  cam.begin(115200);
  cam.attach(ball, simplify);
  ui.begin(115200);
  ui.attach(bnopid, line_test, cam, ball, simplify, attack);
  uss.begin(115200);
  pinMode(motor_pin, OUTPUT);
  bnopid.setup();
  bnopid.set_target();
  attack.attach(bnopid, motor, kick, ball, line_test, simplify, cam);
  attack.begin();
  defence.attach(bnopid, motor, kick, ball, line_test, simplify, cam);
  defence.begin();
  pinMode(comm, INPUT);
  pinMode(comm2, INPUT);
  pinMode(comm3, INPUT);

  esc.begin();
    // while (!Serial) {
  //   // wait for USB serial port to connect (TelePlot / Serial Monitor)
  // }

  digitalWrite(motor_pin, LOW);
}


void loop()
{
  line_test.updateSensor();
  cam.update_Front();
  cam.update_Back();
  cam.update_OMNICAM();
  ball.updateBallSensor();
  ui.update();
  ui.commu(lastResetCause);
  float B_angle = ball.getAngle();
  uss.update();
  // Serial.println(B_angle);
  selected_role = ui.getRole();
  robot_start = ui.getRobotStartRequest();

  
  line_test.setRaw(selected_role);

  if(ui.SetDirRequest() == 1){
    bnopid.set_target();
  }
  if(ui.KickRequest() == 1){
    kick_request = 1;
  }

  // kick_request = 1;
  if(kick_request == 1){
    kick_request = kick.shoot(); 
  }
  // selected_role = 3;
  // robot_start = 1;
  // selected_role = 3;
  // robot_start = 1;
  if(selected_role == 3){          // Attack
    // attack.runSimple(150);
    esc.update();
    if(robot_start == 1){
      if (esc.isReady()) {
        if(300 < B_angle || B_angle < 60){
          esc.setPulseUs(1400);
        }
        else{
          esc.setPulseUs(1500);
        }
      }
    }
    else{
      esc.setPulseUs(1500);
    }
    attack.run();
  }
  else if(selected_role == 4){     // Defence 
    defence.run();
  }
  if((robot_start == 1 || ((digitalRead(comm) == 1) || digitalRead(comm2) == 1) || digitalRead(comm3) == 1) && (selected_role != 0)){
    digitalWrite(motor_pin, HIGH);
  }
  else{
    digitalWrite(motor_pin, LOW);
  }
  // static uint32_t lastBnoPrintMs = 0;
  // if (millis() - lastBnoPrintMs >= 100) {
  //   bnopid.print();
  //   lastBnoPrintMs = millis();     v 
  // }
  // Serial.println(analogRead(A8));
  // Serial.print("here");
}

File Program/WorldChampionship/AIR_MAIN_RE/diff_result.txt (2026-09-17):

Only in .: diff_result.txt
diff -r -x .pio -x .git -x .vscode -x .DS_Store ../AIR_MAIN_DCX/lib/Attack/Attack.cpp ./lib/Attack/Attack.cpp
32,33d31
< 
<   // active_Kick = 1;
53,54c51,52
<   OMNICAM_center = camera->getOMNICAMcenter();
<   OMNICAM_flont = camera->getFrontOMNICAMAngle();
---
>   // OMNICAM_center = camera->getOMNICAMcenter();
>   // OMNICAM_flont = camera->getFrontOMNICAMAngle();
61,75c59,62
<   // Serial.print(isCam_read);
<   // Serial.print(" ");
<   // Serial.println(cam_angle);
<   // if(analogRead(A8) < 800){
<   //   active_Kick = 1;
<   //   // isHold = 1;
<   // }
<   int cam_ball_read     = camera->getBallRead();     // 1: 見えている, 0: ロスト
<   float cam_ball_angle  = camera->getBallAngle();    // 正面を0度とした左右の角度誤差
<   float cam_ball_dist   = camera->getBallDistance(); // カメラからの生距離（0〜250）
<   
<   if(cam_ball_read == 1){
<     if(cam_ball_angle >= 30){
<       Ball_angle = cam_ball_angle;
<     }
---
>   // Serial.println(isHold)
>   if(analogRead(A8) < 400){
>     active_Kick = 1;
>     // isHold = 1;
77,84d63
<   
<   if(Ball_angle == 999){
<     if(cam_ball_read == 1){
<       Ball_angle = cam_ball_angle;
<       // get_Ball_far = cam_ball_dist;
<     }
<   }
<   if(isHold == 1) Ball_angle = 0;
86,91d64
<   // キャリブレーション完了後の通常動作
<   // }
<   // else{
<   //   esc.setPulse(1500);
<   // }
<   // Serial.println(Ball_angle);
117a91
> 
497c471
<         cam_angle = 1 * (float)(thisthis - CENTER_VAL) * (HFOV / 250.0);
---
>         cam_angle = -1 * (float)(thisthis - CENTER_VAL) * (HFOV / 250.0);
499,508c473
<       float now = bnopid->getDIR();
<       if(now >= 0){
<         go_angle = 20;
<       }
<       else if(now < 0){
<         go_angle = 340;
<       }
<       else{
<         go_angle = 0;
<       }
---
>       go_angle = 0;
551,553d515
<     else if(abs(simplify->goPM(Ball_angle)) > 30){ 
<       A = 48;
<     }
590,617d551
<   if(A == 200){ //ホールド待機
<     B = A;
<     if(isHold != 1) A = 10;
<     if(timer_calcBLDC.read_ms() > 800){
<       A = 250;
<       timer_calcBLDC.reset();
<     }
<     read_LINE = 0;
< 
<     if(B == A){
<       motor->calc(180, bnopid->get_pd(0), 0, int(isCatch_Ball_pid), cam_angle);
<     }
<   }
< 
<   if(A == 250){ //引き戻し
<     B = A;
<     if(Line_angle != 999) A = 20;
<     if(isCam_read == 1 || isHold != 1) A = 10;
<     // if(abs(simplify->goPM(Ball_angle)) > 20) A = 48;
<     motor_speed = int(timer_calcBLDC.read_ms() / 20); //スピードを徐々に上げる感じ
<     if(motor_speed > 200){
<       motor_speed = 200;
<     }
<     if(B == A){
<       motor->calc(180, bnopid->get_pd(0), motor_speed, int(isCatch_Ball_pid), cam_angle);
<     }
<   }
< 
619d552
<  
628,633d560
<   if(Ball_angle == 999 && Line_angle == 999){
<     go_angle = 0;
<   }
< 
<   // Serial.println(B);
< 
669,673d595
< 
<         if(isHold == 1){
<           A = 200;
<           timer_calcBLDC.reset();
<         }
683c605
<         pid_angle = bnopid->get_pd(0); 
---
>         pid_angle = bnopid->get_pd(0);
699c621
<     motor->calc(float(go_angle), pid_angle, motor_speed, int(isCatch_Ball_pid), cam_angle);
---
>     motor->calc(float(go_angle), pid_angle, int(motor_speed), int(isCatch_Ball_pid), cam_angle);
diff -r -x .pio -x .git -x .vscode -x .DS_Store ../AIR_MAIN_DCX/lib/Attack/Attack.h ./lib/Attack/Attack.h
86d85
<   TIMER timer_calcBLDC;
diff -r -x .pio -x .git -x .vscode -x .DS_Store ../AIR_MAIN_DCX/lib/BALL/BALL.h ./lib/BALL/BALL.h
49c49
<     const int KICK_VAL = 800;
---
>     const int KICK_VAL = 200;
diff -r -x .pio -x .git -x .vscode -x .DS_Store ../AIR_MAIN_DCX/lib/BNOPID/BNOPID.cpp ./lib/BNOPID/BNOPID.cpp
5,9d4
<   Wire.setSDA(18); // Wire1のSDAピン
<   Wire.setSCL(19); // Wire1のSCLピン
<   Wire.begin();
<   Wire.setClock(400000); 
<   delay(100);
11,13c6,7
<   // I2Cクロックを高速化（Teensy 4.1のパワーを活かす。BNO055はWire1にあるためWire1を設定）
< 
< 
---
>   // I2Cクロックを高速化（Teensy 4.1のパワーを活かす）
>   Wire.setClock(400000); 
22,24c16
<   // getEventの代わりに軽量なgetVectorを使用
<   imu::Vector<3> euler = bno.getVector(Adafruit_BNO055::VECTOR_EULER);
<   event.orientation.x = euler.x();
---
>   bno.getEvent(&event);
77,80c69
<   // 制御周期を5ms（200Hz）に高速化
<   if (now_ms - last_bno_read < 5) return last_pid;
<   double dt_sec = (now_ms - last_bno_read) / 1000.0;
<   if (dt_sec <= 0.0) dt_sec = 0.001; // ゼロ除算防止の防御的コード
---
>   if (now_ms - last_bno_read < 10) return last_pid;
83,88c72,73
<   // 1. 通信と角度取得（軽量なgetVectorを用いて物理読み出しのオーバーヘッドを削減）
<   imu::Vector<3> euler = bno.getVector(Adafruit_BNO055::VECTOR_EULER);
<   event.orientation.x = euler.x();
<   
<   // 物理的なロボットの向き（adderを含まない実測値）と、目標を含めたNow_DIRを取得
<   double physical_DIR = get_x(0);
---
>   // 1. 通信と角度取得
>   bno.getEvent(&event);
96c81
<   // 3. I分の計算（ダイナミックdtを適用）
---
>   // 3. I分の計算（必要な時だけ溜める）
98c83
<     i += p * dt_sec; 
---
>     i += p * 0.01; // dt=10ms固定
104,120c89,91
<   // 4. D分の計算（微分先行型：測定値の微分を用いて目標値変更によるキックを防止）
<   static double pre_physical_DIR = 0;
<   static bool first_run = true;
<   if (first_run) {
<     pre_physical_DIR = physical_DIR;
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

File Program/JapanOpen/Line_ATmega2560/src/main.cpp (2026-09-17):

#include <Arduino.h>

// ピン情報の定義
volatile uint8_t* pins[] = {
  &PIND, &PIND, &PINL, &PINL, &PINL, &PINL, &PINH, &PINH,
  &PINH, &PINH, &PINH, &PINH, &PINJ, &PINJ, &PINJ, &PINJ,
  &PINJ, &PINC, &PINC, &PINC, &PINC, &PINC, &PINC, &PINC
};

uint8_t bits[] = {
  7, 6, 7, 6, 5, 4, 6, 5,
  4, 3, 2, 1, 7, 6, 5, 4,
  3, 7, 6, 5, 4, 3, 2, 1
};

// デバッグ表示用関数
void debugPrint(uint8_t b0, uint8_t b1, uint8_t b2, uint8_t side_grid);

void setup() {
  Serial.begin(9600);  // PCデバッグ用
  Serial1.begin(115200); // Teensy通信用
  // 入力ピン初期化
  DDRA &= ~(_BV(PA2) | _BV(PA6) | _BV(PA5));
  DDRD &= ~(_BV(PD7) | _BV(PD6));
  DDRL &= ~(_BV(PL7) | _BV(PL6) | _BV(PL5) | _BV(PL4));
  DDRH &= ~(_BV(PH6) | _BV(PH5) | _BV(PH4) | _BV(PH3) | _BV(PH2) | _BV(PH1));
  DDRJ &= ~(_BV(PJ7) | _BV(PJ6) | _BV(PJ5) | _BV(PJ4) | _BV(PJ3) | _BV(PJ0));
  DDRC &= ~(_BV(PC7) | _BV(PC6) | _BV(PC5) | _BV(PC4) | _BV(PC3) | _BV(PC2) | _BV(PC1));
  DDRF &= ~(_BV(PF0) | _BV(PF1) | _BV(PF3) | _BV(PF6));
  DDRK &= ~(_BV(PK0) | _BV(PK1) | _BV(PK4) | _BV(PK5) | _BV(PK6));
  pinMode(5, OUTPUT);
  TCCR3B = (TCCR3B & 0xF8) | 0x01; 
  analogWrite(5, 85); //26朝150 //80
}

void loop() {
  // unsigned long startTime = micros(); // 開始（マイクロ秒） 
  // 1. ラインセンサーパッキング
  uint8_t b0 = 0, b1 = 0, b2 = 0;
  for (int i = 0; i < 8; i++)  if ((*pins[i] >> bits[i]) & 0x01) b0 |= (1 << i);
  for (int i = 8; i < 16; i++) if ((*pins[i] >> bits[i]) & 0x01) b1 |= (1 << (i - 8));
  for (int i = 16; i < 24; i++)if ((*pins[i] >> bits[i]) & 0x01) b2 |= (1 << (i - 16));

  // 2. サイド & Gridパッキング
  uint8_t side_grid = 0;
  if ((PINA >> 2) & 0x01) side_grid |= (1 << 7); // F
  if ((PINF >> 6) & 0x01) side_grid |= (1 << 6); // L
  if ((PINA >> 6) & 0x01) side_grid |= (1 << 5); // R
  if ((PINA >> 5) & 0x01) side_grid |= (1 << 4); // B

  if (((PINF >> 0) | (PINF >> 1) | (PINF >> 3)) & 0x01) side_grid |= (1 << 3); // GL
  // if (((PINK >> 0) | (PINK >> 1) | (PINJ >> 0)) & 0x01) side_grid |= (1 << 2); // GR
  if (((PINK >> 4) | (PINK >> 5) | (PINK >> 6)) & 0x01) side_grid |= (1 << 1); // GB

  // 3. パケット送信 (6バイト)
  Serial1.write(255);       // Header
  Serial1.write(b0);
  Serial1.write(b1);
  Serial1.write(b2);
  Serial1.write(side_grid);
  Serial1.write(128);       // Footer

  // debugPrint(b0, b1, b2, side_grid);
}

// デバッグ用関数：シリアルモニタで人間が読みやすい形式で表示
void debugPrint(uint8_t b0, uint8_t b1, uint8_t b2, uint8_t side_grid) {
  static uint32_t lastPrint = 0;
  if (millis() - lastPrint < 50) return; // 表示が速すぎて読めないのを防ぐ(20Hz)
  lastPrint = millis();

  Serial.print("L:");
  // 24bit分をバイナリ表示
  for(int i=0; i<8; i++) Serial.print((b0 >> i) & 1);
  for(int i=0; i<8; i++) Serial.print((b1 >> i) & 1);
  for(int i=0; i<8; i++) Serial.print((b2 >> i) & 1);

  Serial.print(" | S(FLRB):");
  Serial.print((side_grid >> 7) & 1);
  Serial.print((side_grid >> 6) & 1);
  Serial.print((side_grid >> 5) & 1);
  Serial.print((side_grid >> 4) & 1);

  Serial.print(" | G(LRB):");
  Serial.print((side_grid >> 3) & 1);
  Serial.print((side_grid >> 2) & 1);
  Serial.print((side_grid >> 1) & 1);
  Serial.println();
}

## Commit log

2026-09-17 Add new project
    [AIR_2026_Robot_ATK.f3z, AIR_2026_Robot_DEF.f3z, Ball_V4_32u4.kicad_pcb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]
2026-09-17 Convert all submodules to normal folders and upload code
    [diff_result.txt]
2026-09-19 コメントアウト汚すぎ笑えん
2026-09-19 カメラプログラム追加
